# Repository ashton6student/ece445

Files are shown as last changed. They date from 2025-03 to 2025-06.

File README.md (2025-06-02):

# VR Gloves Project

Note: each subfolder has its own `README.md` file that forms the ECE 445 notebook, in addition to this top-level file.

## Overview

The VR Gloves project aims to create a pair of wearable hand-tracking gloves for VR applications, compatible with popular VR systems like Meta Quest 2. The gloves utilize perpendicular Hall effect sensors and magnets for finger flex tracking, a servo-based haptic feedback system, and BLE communication to interact with Unity applications.

## Inspirations

This project is inspired by LucidGloves, an open-source VR glove. This project specifically attempts to take the good things from V3 and the good things from V5 to make our own unique solution. Specifically, it uses the badge reel idea from V3 and the hall-effect magnet solution from the V5 and combines them together.

## Problem Statement

Modern VR devices often rely on handheld controllers that do not fully immerse the user in the virtual environment. While some high-end solutions like the Valve Index offer partial finger tracking, most affordable options still use conventional button-based input. The goal of this project is to develop a more immersive and affordable solution using DIY components.

## Key Features

- **Wireless Communication:** Uses BLE to transmit hand data to Unity applications.
- **Finger Tracking:** Perpendicular Hall effect sensors measure finger curl using magnetic field angle changes.
- **Haptic Feedback:** Servo motors lock the badge reels, restricting finger movement to provide haptic feedback.
- **Integrated VR Interaction:** Uses Unity's XR Interaction Toolkit to allow for these gloves to be developed in a VR scene and can be deployed to a VR headset.

## System Design

The VR gloves consist of five main subsystems:

### 1. Power Subsystem

- Uses a 7.4V Li-ion battery stepped down to 5V and 3.3V using LDO regulators.
- Provides stable power for ESP32-S3, hall effect sensors, and servo motors.

### 2. Sensor Subsystem

- Perpendicular Hall effect sensors paired with magnets on each finger track the degree of bend.
- Quest Controller used for hand positioning.
- Haptic feedback provided by servos locking badge reels.

### 3. MCU Subsystem

- Uses ESP32-S3 for data acquisition, BLE communication, and haptic control.
- Converts raw sensor data into a usable format in Unity.
- Transmits data via BLE to Unity with low latency (<20ms).

### 4. Controller Subsystem

- Features a thumb joystick and push buttons mounted on the index finger.
- Allows for conventional VR controller actions.
- Data is transmitted to Unity using the BLE protocol.

### 5. Software Subsystem

- Integrates with Unity using the XR Interaction Toolkit for virtual scene deployment.
- Virtual scene containing objects with colliders to test interaction.
- BLE data mapped to virtual hand movements and actions.
- Collision detection triggers haptic feedback via BLE.

## Code Structure

```
project_root/
├── Unity Files/       # Unity project and scenes
├── PCB Files/         # PCB schematics and board files
├── Arduino Files/     # Arduino sketches for glove firmware
├── 3D Files/          # 3D models and assets for Unity
├── Bluetooth Files/   # BLE communication scripts and libraries
├── myenv/             # Virtual environment for Python utilities
└── README.md          # Project documentation
```

### Arduino Files and Bluetooth Files

- Contains Arduino sketches for ESP32 to handle BLE communication and haptic control.
- Implements data acquisition from Hall effects and joystick inputs.
- Supports BLE wireless communication for real-time data transfer.

### Unity Files

- Unity scripts for receiving BLE data and controlling virtual hands.
- Includes a test scene for verifying glove performance.

### 3D Files

- 3D files for the glove parts.

### PCB Files

- KiCAD files for the PCBs in our project.

## Installation

1. Flash the ESP32 with the provided firmware in the `firmware/glove_controller/` directory.
2. Run the BLE Python bridge script located in `Bluetooth Files/`. You may need com2com software to simulate serial ports. Be sure to activate the Python virtual environment in `myenv/` and install required packages.
3. Open the Unity project from the `Unity Files/` folder.
4. Run the scene to test the glove inputs.

## Usage

- Wear the gloves and ensure they are powered on.
- Start the Unity scene and observe hand movement tracking.
- Test grabbing and manipulating virtual objects to validate haptic feedback.

## Future Improvements

- Enhanced haptic feedback.
- Integration with more VR platforms like SteamVR.
- Improved latency optimization in BLE communication.

## Authors

- Ashton Billings
- Hamza Lutfi
- Aditya Nebhrajani

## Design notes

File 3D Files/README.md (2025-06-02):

# 3D Files

## Project Overview

This folder contains a collection of 3D model files for various components for the VR glove project. The files are organized into subfolders based on their functionality or component type. Take the most recent version as the current working version.

## Directory Structure

```
3D Files/
├── ReelCoin/
├── FingerTip/
├── HapticsSystem/
├── BreadboardMount/
├── ReelGuide/
├── GloveMount/
└── Z.Misc/
```

### Subfolder Descriptions

- **ReelCoin/**: Contains STL files for different versions of a circular reel coin component.
- **FingerTip/**: Various iterations of the fingertip component.
- **HapticsSystem/**: 3D models for the haptic feedback system, containing several versioned files.
- **BreadboardMount/**: Models for mounting the PCB, battery, and related electronics.
- **ReelGuide/**: STL files for guiding or housing reels, with multiple versions available.
- **GloveMount/**: Mounting components for a glove-based setup, with multiple iterations.
- **Z.Misc/**: Miscellaneous components, including custom reels, gear models, and a pot holder.

## Usage

1. Inspect the STL files using 3D modeling software (e.g., Blender, Fusion 360) to verify dimensions.
2. Print using a 3D printer with compatible filament (e.g., PLA, ABS).
3. Adjust the model scale and orientation as needed before slicing.

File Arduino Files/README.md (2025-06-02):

# Arduino Project README

## Project Overview

This folder contains various Arduino-based test sketches used throughout the development of the VR glove system. Each subfolder represents a different development or testing checkpoint. While several sketches were created for experimenting with sensor inputs, BLE, and motor control, the current active version is located in the `ece445Arduino5` folder.

### Components:

- ESP32 microcontroller
- Joystick module
- Push buttons
- Servo motor
- Potentiometer

### Development History

```
Arduino Files/
├── ece445PlatformIO/                # PlatformIO testing checkpoint for ESP32
│   ├── src/                         # Source files
│   │   └── main.cpp                 # Main application code
│   └── platformio.ini               # PlatformIO configuration file
├── ArduinoInoFiles/                 # Traditional Arduino sketches
│   ├── ece445Arduino/               # Initial sketch
│   │   └── ece445Arduino.ino        # Primary Arduino sketch
│   ├── ece445Arduino2/              # Development checkpoints
│   ├── ece445Arduino3/              # Development checkpoints
│   ├── ece445Arduino4/              # Development checkpoints
│   ├── ece445Arduino5/              # Current BLE version
│   └── ece445Arduino6/              # Current serial version
```

## Installation

1. Clone or download the repository.
2. Open the desired `.ino` file in the Arduino IDE:
   - Use `ece445Arduino5` for BLE communication.
   - Use `ece445Arduino6` for serial communication.
3. Connect your ESP32 board to your computer via USB.
4. In the Arduino IDE, select the correct board type and COM port.
5. Click the Upload button to flash the code to your ESP32.

## Usage

The firmware sketches support both BLE (Bluetooth Low Energy) and wired serial communication, enabling wireless data transmission and control.

1. Upon startup, the ESP32 initializes the sensors and sets up the joystick and servo control.
2. Joystick data and button states are transmitted over serial at 115200 baud.
3. Use the joystick to control the servo and monitor sensor readings in the serial monitor.
4. BLE support can be integrated from `../Bluetooth Files`.

## Dependencies

- Arduino framework for ESP32
- ESP32Servo library

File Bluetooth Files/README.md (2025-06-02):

# Bluetooth Serial Bridge and ESP32 BLE API

## Overview

This folder consists of a Bluetooth serial bridge for communication between an ESP32 device and a host machine, along with an ESP32 Bluetooth API for setting up BLE communication. The folder is divided into two main components:

1. **Bluetooth Serial Bridge (Python)** - Establishes a Bluetooth connection between the ESP32 and a host PC.
2. **ESP32 Bluetooth API (Arduino)** - Sets up a BLE server on the ESP32 to facilitate communication with the host PC.

## Folder Structure

```
Bluetooth Files/
├── bluetooth_serial_bridge/
│   ├── bluetooth_serial_bridge.py        # Python script for Bluetooth serial bridge
│   └── test_bridge_legacy_app.py         # Placeholder for future integration with Unity's legacy COM code
└── esp32_bluetooth_api/
    └── bluetooth_api/
        └── bluetooth_api.ino             # Arduino sketch for BLE communication on ESP32
```

## Features

- Bidirectional Bluetooth communication using BLE.
- Virtual serial port support for both Windows and macOS.
- Real-time data transmission between the host and ESP32.

## Setup Instructions

### Prerequisites

- Python 3.8+
- `bleak` library for Bluetooth communication
- `pyserial` library for serial communication
- Arduino IDE for programming the ESP32

### Installing Dependencies

```bash
pip install bleak pyserial
```

### Running the Bridge

1. Upload the `bluetooth_api.ino` to your ESP32 using the Arduino IDE.
2. Run the Python bridge script:

```bash
python bluetooth_serial_bridge.py
```

3. Use the test script to send messages:

```bash
python test_bridge_legacy_app.py
```

## Usage

- The bridge script will automatically detect the OS and set up a virtual serial port.
- The test script sends user-inputted strings and displays responses from the ESP32.

## Troubleshooting

- Ensure that the COM port is correctly configured in the script for Windows.
- Check the BLE device name and UUIDs if connection fails.

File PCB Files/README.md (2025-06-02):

# PCB Project Overview

This repository contains the design files for two PCBs: **ESP32** and **Hall-Effect Sensor**. Both projects were designed using KiCad and include schematic files, PCB layouts, backups, and Gerber files for manufacturing.

## Project Structure

The repository is structured as follows:

```
PCB Files/
├── ESP32/
│   ├── ESP32.kicad_pcb           # PCB layout file
│   ├── ESP32.kicad_sch           # Schematic file
│   ├── ESP32.kicad_pro           # KiCad project file
│   ├── gerbers/                  # Gerber files for PCB manufacturing
│   └── backups/                  # Backup versions of the project
├── hall-effect/
│   ├── hall-effect.kicad_pcb     # PCB layout file
│   ├── hall-effect.kicad_sch     # Schematic file
│   ├── hall-effect.kicad_pro     # KiCad project file
│   ├── gerbers/                  # Gerber files for PCB manufacturing
│   └── backups/                  # Backup versions of the project
└── __MACOSX/                     # System-generated files (can be ignored)
```

## ESP32 Project

The ESP32 PCB project is designed around the ESP32 microcontroller, featuring:

- BLE and Wi-Fi connectivity
- GPIO headers for peripherals
- Power management circuits

### Gerber Files

The Gerber files located in `ESP32/gerbers/` include:

- Copper layers (F_Cu, B_Cu)
- Silkscreen layers (F_Silkscreen, B_Silkscreen)
- Solder mask layers (F_Mask, B_Mask)
- Paste layers (F_Paste, B_Paste)
- Edge cuts for board outline
- Drill files (PTH, NPTH)

## Hall-Effect Project

This project is based on a Hall-effect sensor module, designed for magnetic field detection.

- Uses a Hall-effect sensor IC
- Signal conditioning circuitry
- Gerber Files

Similar structure to the ESP32 project with copper, silkscreen, mask, paste, edge cuts, and drill files.

## Backups

The `backups/` directories in each project folder contain automated KiCad backups, timestamped for version tracking.

## Usage

Open the project files using KiCad (version 6.x or later). To fabricate the PCBs, use the Gerber files located in the respective `gerbers/` folder.

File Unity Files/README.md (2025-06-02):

# Unity VR Project

## Overview

This Unity VR project is built using the XR Interaction Toolkit (version 3.0.7) and showcases a hand interaction demo. It serves as a foundational project for VR environments with hand tracking, hand-based interaction, and gesture control.

## Features

- **XR Interaction Toolkit (3.0.7)**: Utilizes Unity's toolkit for VR interaction.
- **Hands Interaction Demo**: Demonstrates the use of hand tracking, poke gestures, and interaction affordances.
- **VR Hand Rig**: Configured hand tracking for left and right hands with visual affordances.
- **Prefab Assets**: Includes various prefabs for hand interaction visualization and UI elements.
- **Custom Scripts**:
  - TransformSync.cs: Synchronizes object transformations.
  - ToggleGameObject.cs: Manages visibility toggling of objects.
  - PokeBlendShapeAnimator.cs: Animates hand poke gestures.
  - CollisionLogger.cs: Logs collisions detected by objects.
  - SerialFloatReader.cs: Reads floating-point data from a serial device.

## Installation

1. Clone the project to your Unity projects directory.
2. Open the project in Unity (version 2021.3 or higher recommended).
3. Import the XR Interaction Toolkit package via Unity Package Manager.

## Usage

- Load the `HandsDemoScene` from the `Assets/Samples/XR Interaction Toolkit/3.0.7/Hands Interaction Demo` folder.
- Press Play to explore the VR environment and interact with objects using hand gestures.
- Connect the VR headset and controllers to enable hand tracking.

## Scripts

- **HandsOneEuroFilterPostProcessor.cs**: Implements a post-processing filter for hand data.
- **PokeGestureDetector.cs**: Detects poke gestures and triggers associated actions.
- **PinchPointFollow.cs**: Updates the position of objects based on pinch gestures.
- **ObjectResetPlane.cs**: Resets objects to their initial positions when dropped.

## Troubleshooting

- Ensure the correct version of the XR Interaction Toolkit is installed.
- Verify that the VR headset is properly connected and configured.

## License

This project follows the standard Unity Asset Store license for included assets.

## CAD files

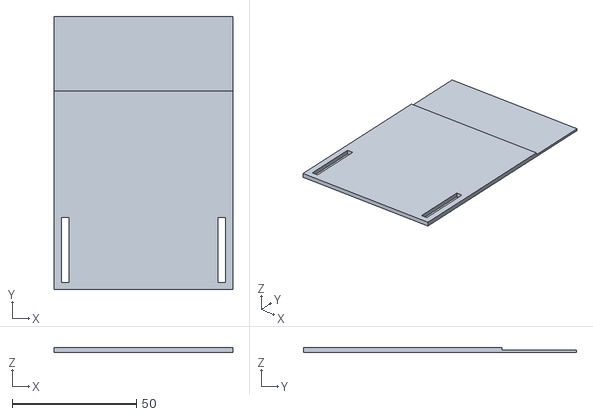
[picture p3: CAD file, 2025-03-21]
3D Files/BreadboardMount/BreadboardPlateV2.stl
72.0 x 110.0 x 2.00

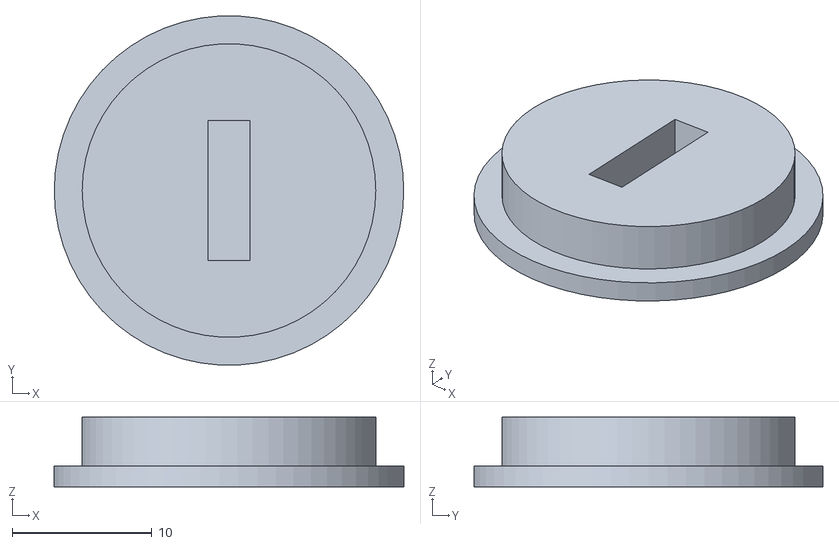
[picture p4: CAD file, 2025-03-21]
3D Files/ReelCoin/ReelCoinHallV1.stl
25.0 x 25.0 x 5.00

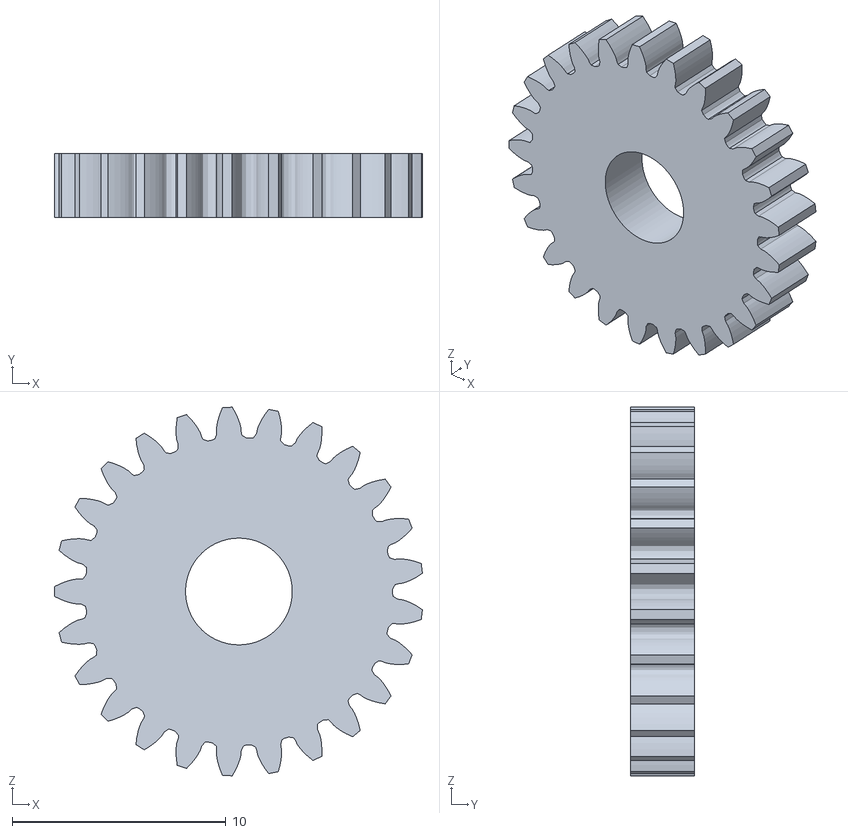
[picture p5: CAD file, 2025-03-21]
3D Files/Z.Misc/GearV1.stl
17.2 x 3.00 x 17.3

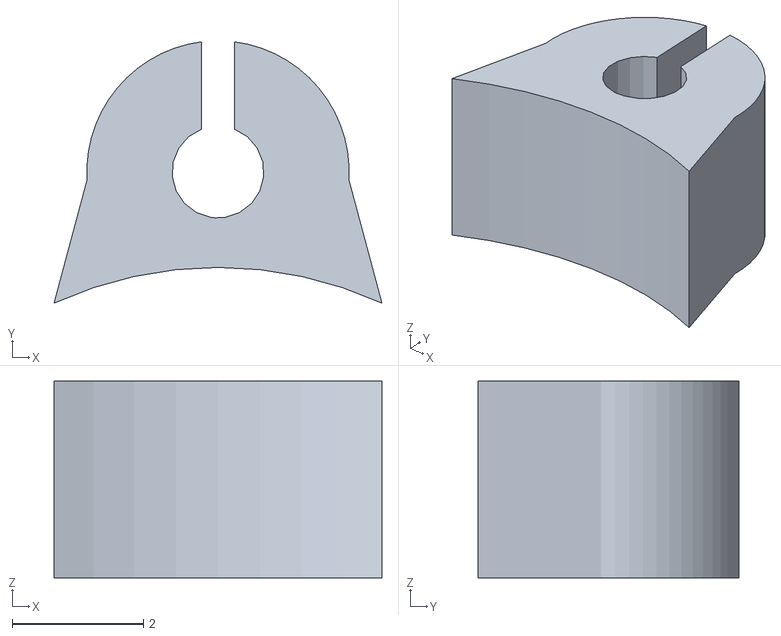
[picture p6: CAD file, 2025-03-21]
3D Files/Z.Misc/testreel.stl
5.00 x 3.98 x 3.00

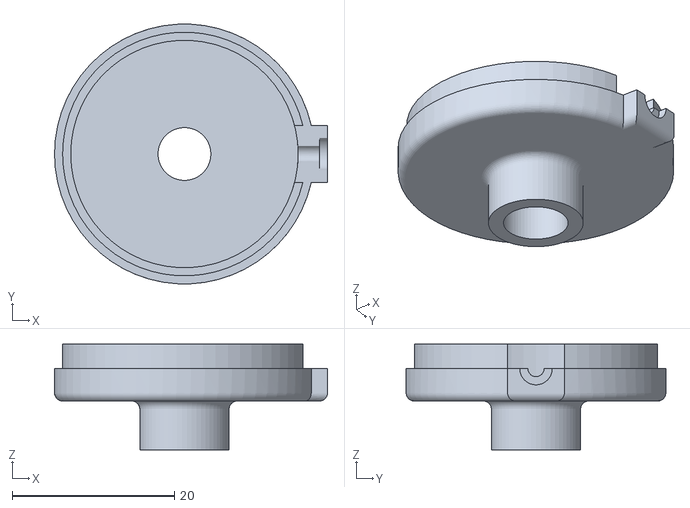
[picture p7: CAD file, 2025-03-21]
3D Files/Z.Misc/PotHolderV1.stl
33.6 x 32.0 x 13.0

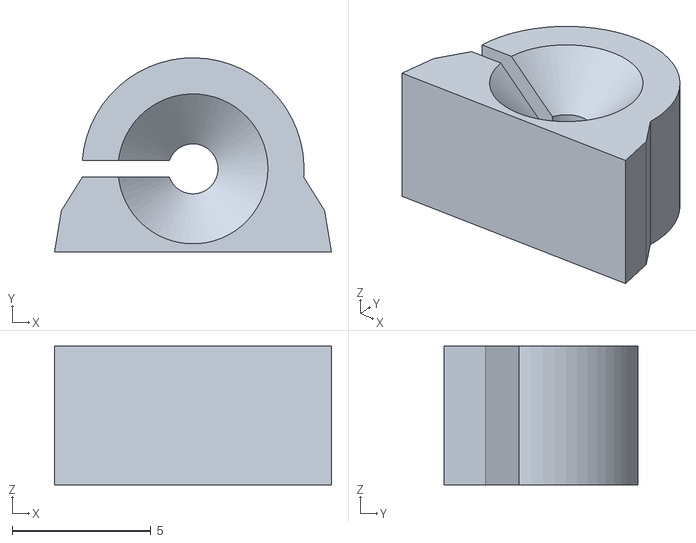
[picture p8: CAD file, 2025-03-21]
3D Files/ReelGuide/ReelV5.stl
9.98 x 7.00 x 5.00

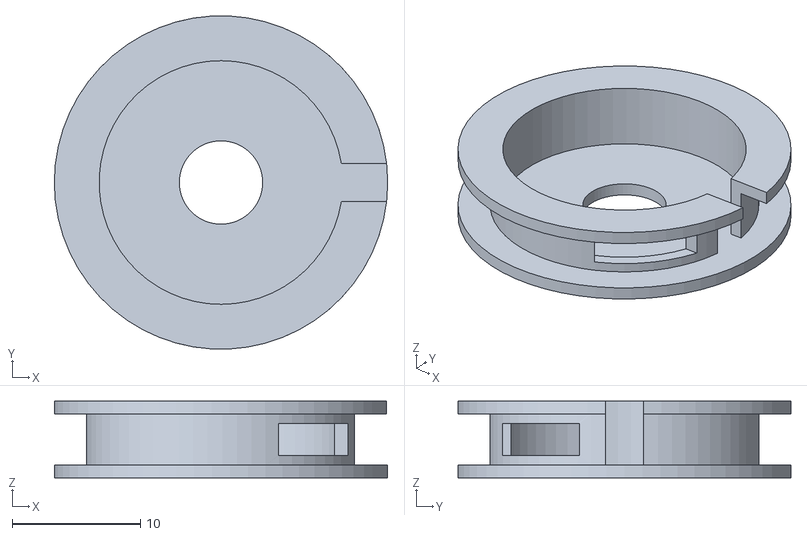
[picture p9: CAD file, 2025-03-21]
3D Files/Z.Misc/CustomReelV2.stl
26.0 x 26.0 x 6.00

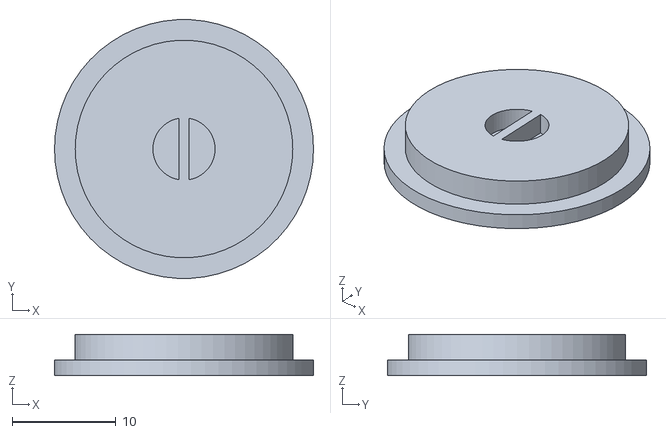
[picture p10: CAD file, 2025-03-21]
3D Files/ReelCoin/ReelCoinV9.stl
25.0 x 25.0 x 4.00

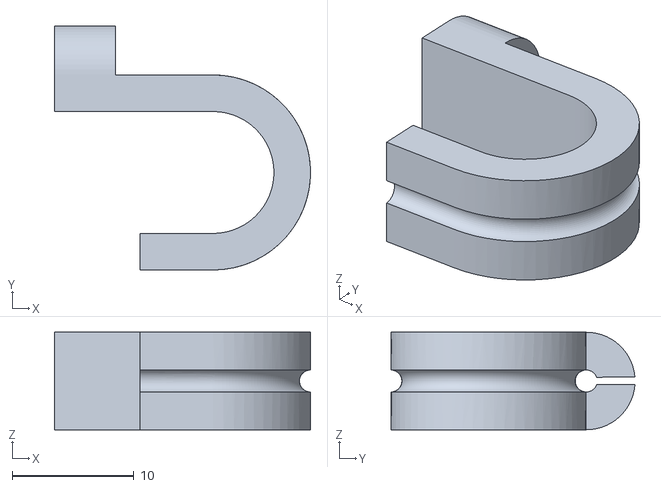
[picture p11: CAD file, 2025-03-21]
3D Files/FingerTip/FingerTipV10.stl
21.0 x 20.0 x 8.00

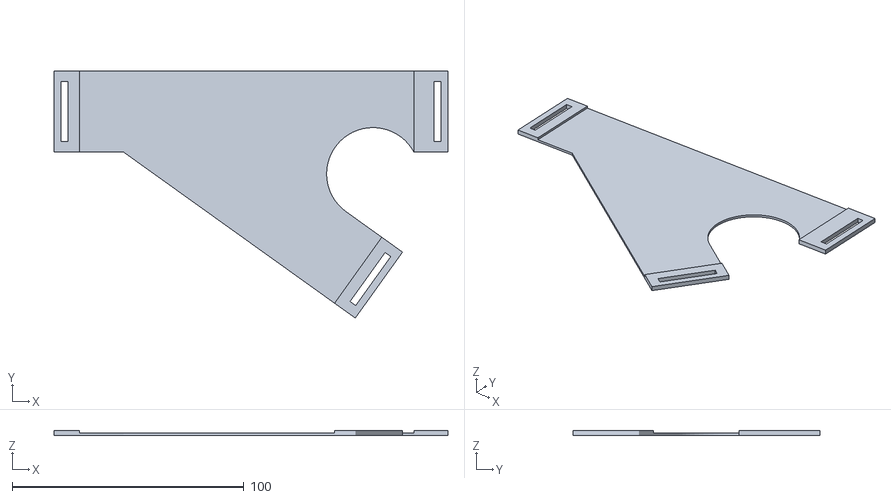
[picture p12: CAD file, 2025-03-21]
3D Files/GloveMount/PlateV9.stl
170.0 x 106.6 x 2.00

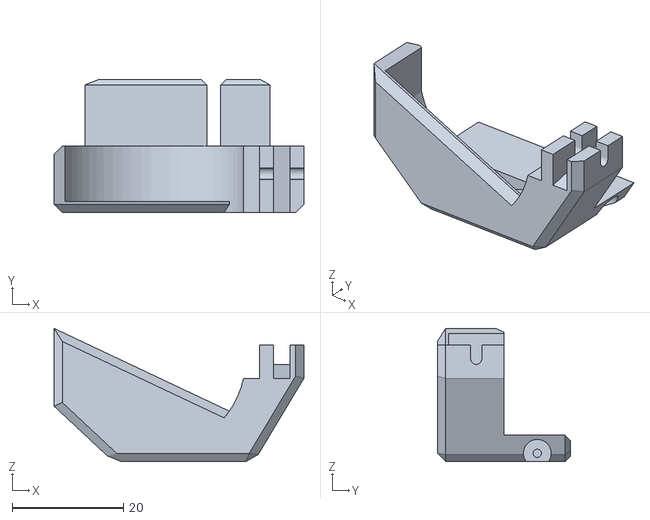
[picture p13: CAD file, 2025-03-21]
3D Files/HapticsSystem/HapticsSystemV9.stl
45.0 x 24.0 x 24.0

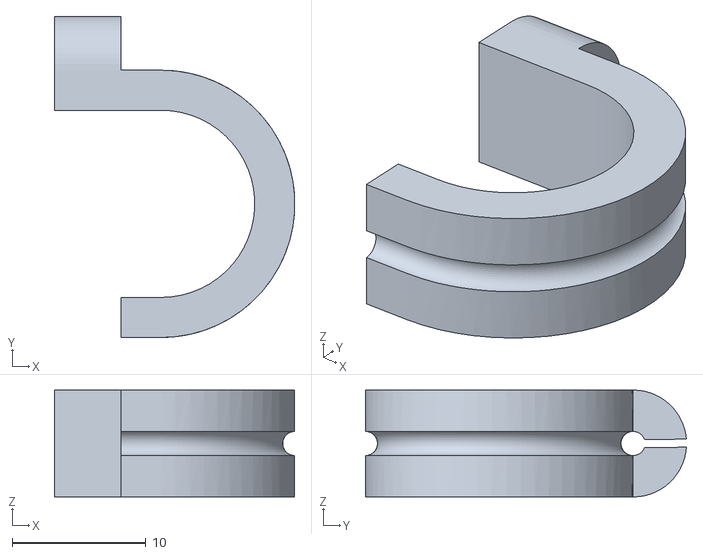
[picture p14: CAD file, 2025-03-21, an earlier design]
3D Files/FingerTip/FingerTipV8.stl
18.0 x 24.0 x 8.00

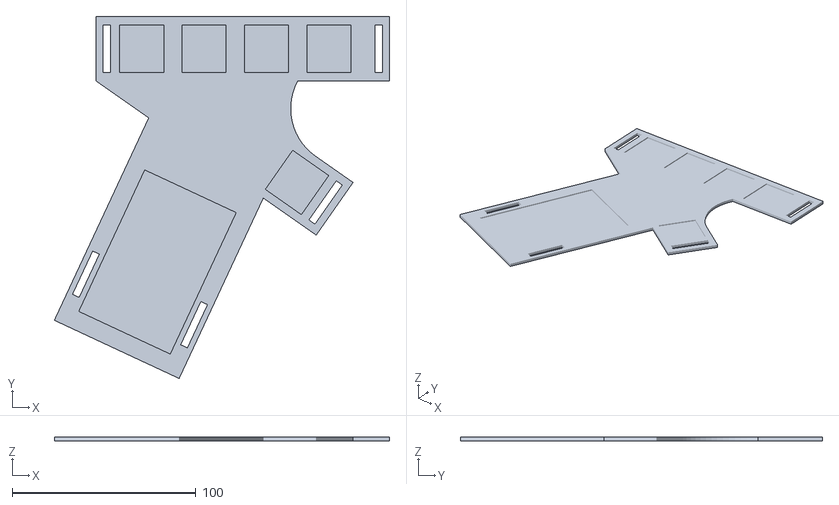
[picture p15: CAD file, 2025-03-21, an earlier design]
3D Files/GloveMount/PlateV8.stl
182.6 x 197.1 x 2.00

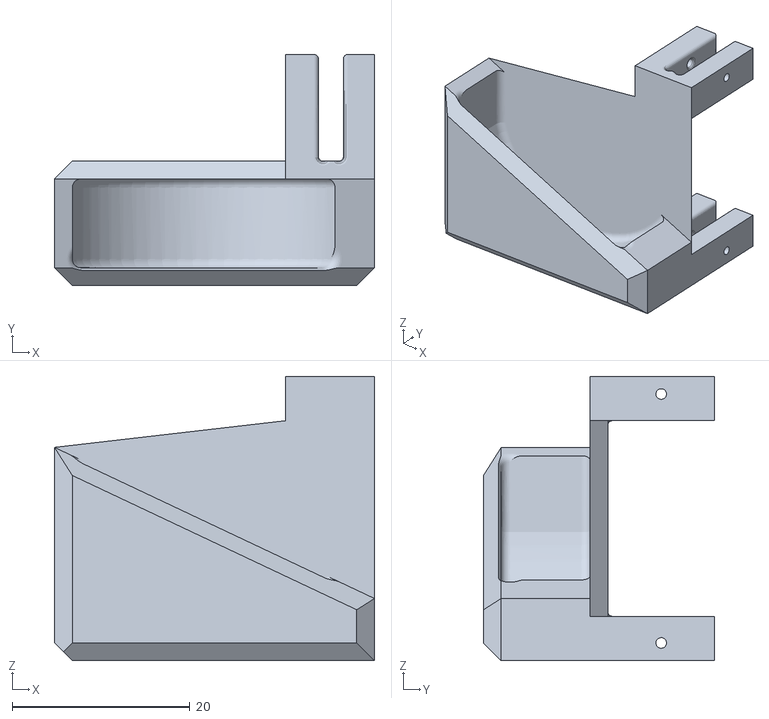
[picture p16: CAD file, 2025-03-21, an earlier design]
3D Files/HapticsSystem/HapticsSystemV1.stl
36.0 x 26.0 x 32.0

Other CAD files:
3D Files/ReelGuide/ReelV2.stl
3D Files/Z.Misc/CustomReelV1.stl
3D Files/BreadboardMount/BreadboardPlateV1.stl
3D Files/FingerTip/FingerTipV4.stl
3D Files/FingerTip/FingerTipV1.stl
3D Files/FingerTip/FingerTipV2.stl
3D Files/FingerTip/FingerTipV3.stl
3D Files/FingerTip/FingerTipV5.stl
3D Files/FingerTip/FingerTipV6.stl
3D Files/FingerTip/FingerTipV7.stl
3D Files/FingerTip/FingerTipV9.stl
3D Files/GloveMount/PlateV1.stl
3D Files/GloveMount/PlateV2.stl
3D Files/GloveMount/PlateV3.stl
3D Files/GloveMount/PlateV4.stl
3D Files/GloveMount/PlateV5.stl
3D Files/GloveMount/PlateV6.stl
3D Files/GloveMount/PlateV7.stl
3D Files/HapticsSystem/HapticsSystemV2.stl
3D Files/HapticsSystem/HapticsSystemV3.stl
3D Files/HapticsSystem/HapticsSystemV4.stl
3D Files/HapticsSystem/HapticsSystemV5.stl
3D Files/HapticsSystem/HapticsSystemV6.stl
3D Files/HapticsSystem/HapticsSystemV7.stl
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

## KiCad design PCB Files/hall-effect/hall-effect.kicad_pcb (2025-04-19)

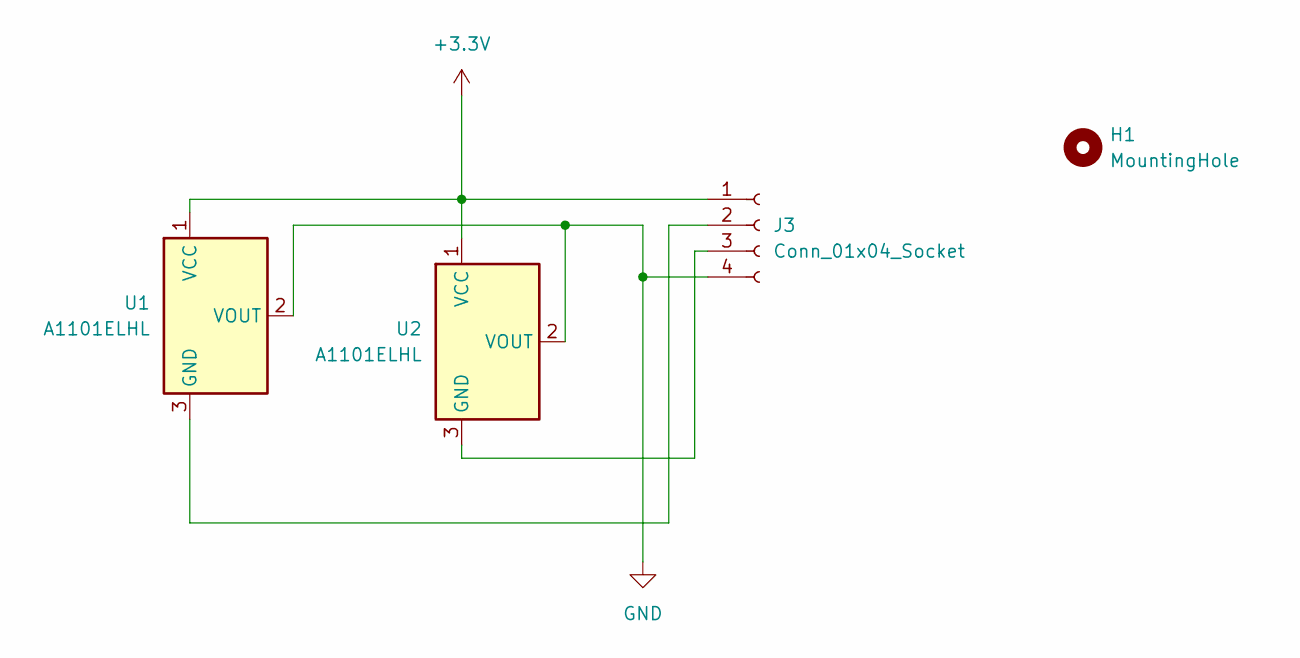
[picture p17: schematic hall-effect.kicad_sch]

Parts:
H1: MountingHole; MountingHole_2.2mm_M2
J3: Conn_01x04_Socket; JST_PH_S4B-PH-K_1x04_P2.00mm_Horizontal
U1, U2: A1101ELHL; TO-92Flat

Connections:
+3.3V: J3.1, U1.1 (VCC), U2.1 (VCC)
GND: J3.4, U1.2 (VOUT), U2.2 (VOUT)
unnamed: J3.2, U1.3 (GND)
unnamed: J3.3, U2.3 (GND)

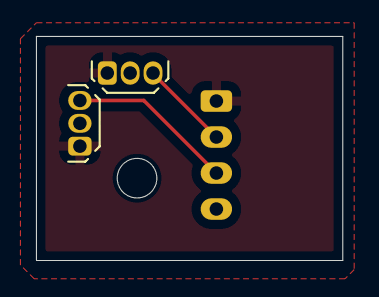
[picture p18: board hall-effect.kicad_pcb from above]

Board: 2 copper layers, 17.0 x 12.4 mm, 4 parts (1 on the bottom side), 4 nets.

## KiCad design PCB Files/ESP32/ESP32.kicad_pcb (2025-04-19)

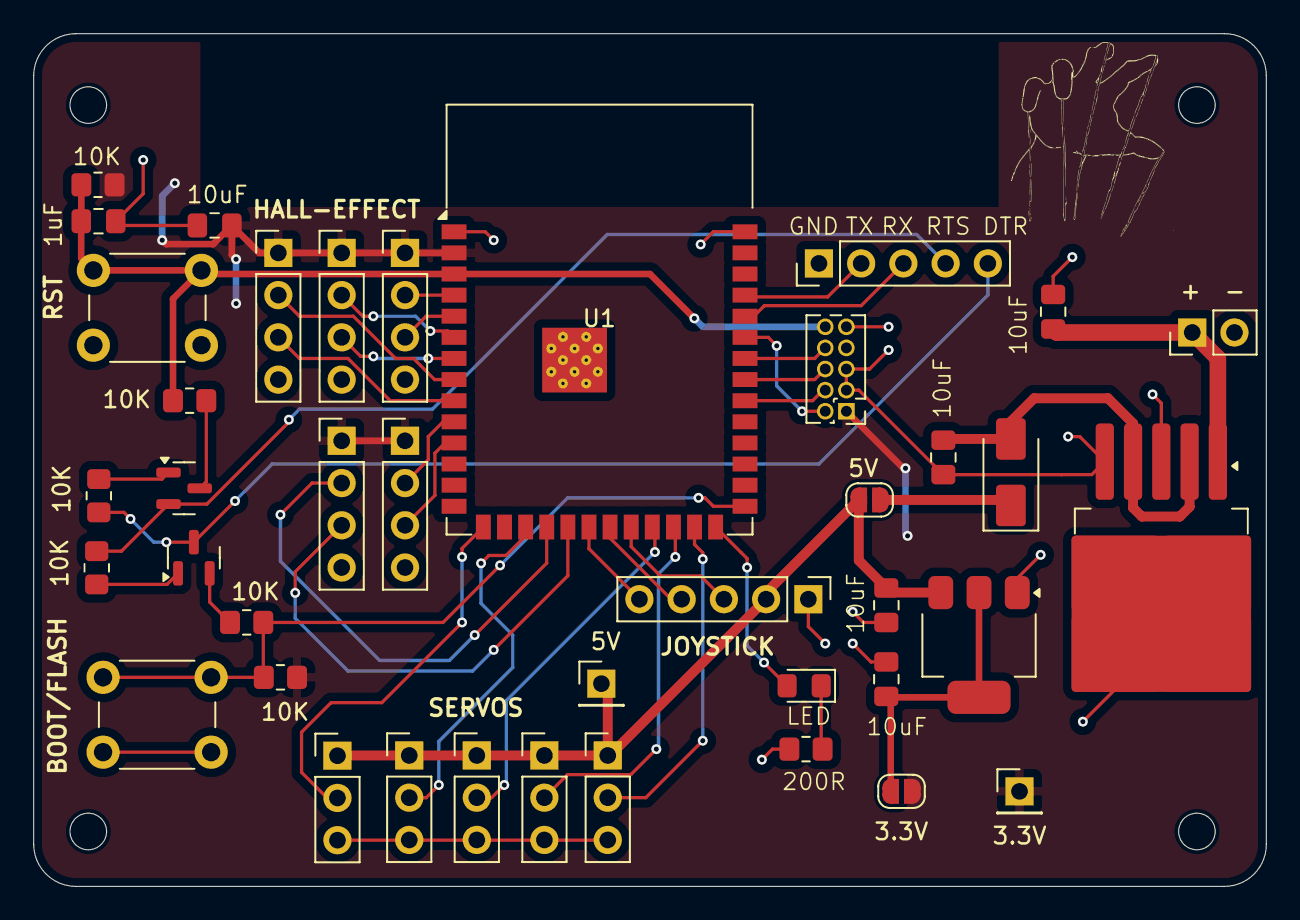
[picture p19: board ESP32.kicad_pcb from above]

Board: 2 copper layers, 74.1 x 51.3 mm, 44 parts (0 on the bottom side), 41 nets.

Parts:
+: 2S LiPo 7.4V 2000mAh; PinHeader_1x02_P2.54mm_Vertical
C1: 1uF; C_0805_2012Metric_Pad1.18x1.45mm_HandSolder
C2, C3, C5, C6, C7: 10uF; C_0805_2012Metric_Pad1.18x1.45mm_HandSolder
D1: LED; LED_0805_2012Metric_Pad1.15x1.40mm_HandSolder
D2: D_Schottky; D_SMA
H1, H2, H3, H4: MountingHole; MountingHole_2.2mm_M2
J1, J2, J3, J4, J5: Conn_01x03_Pin; PinHeader_1x03_P2.54mm_Vertical
J6, J11: Conn_01x05_Pin; PinHeader_1x05_P2.54mm_Vertical
J7: Conn_ARM_JTAG_SWD_10; PinHeader_2x05_P1.27mm_Vertical
J12, J13, J14, J15, J16: Conn_01x04_Pin; PinHeader_1x04_P2.54mm_Vertical
JP1, JP2: SolderJumper_2_Open; SolderJumper-2_P1.3mm_Open_RoundedPad1.0x1.5mm
Q1, Q2: SS8050; SOT-23
R1, R2, R3, R4, R8, R9: 10k; R_0805_2012Metric_Pad1.20x1.40mm_HandSolder
R5: 200; R_0805_2012Metric_Pad1.20x1.40mm_HandSolder
SW1, SW2: SW_Push; SW_PUSH_6mm
TP1, TP2: TestPoint; PinHeader_1x01_P2.54mm_Vertical
U1: ESP32-S3-WROOM-1
U2: AMS1117-3.3; SOT-223-3_TabPin2
U3: LM2596S-5; TO-263-5_TabPin3

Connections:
+3.3V: C7.2, J7.1 (VTref), J12.1, J13.1, J14.1, J15.1, J16.1, JP2.2 (B), R1.1, R4.2, TP2.1, U1.2 (3V3)
+5V: C3.1, J1.1, J2.1, J3.1, J4.1, J5.1, J11.2, JP1.2 (B), TP1.1, U2.3 (VI)
/0ADC: J13.3, U1.19 (IO11)
/1ADC: J11.5, U1.20 (IO12)
/2ADC: J11.4, U1.21 (IO13)
/3ADC: J11.3, U1.22 (IO14)
/4ADC: J15.2, U1.8 (IO15)
/5ADC: J15.3, U1.9 (IO16)
/6ADC: J16.2, U1.10 (IO17)
/7ADC: J16.3, U1.11 (IO18)
/21: J3.2, U1.23 (IO21)
/45: D1.2 (A), U1.26 (IO45)
/47: J4.2, U1.24 (IO47)
/48: J5.2, U1.25 (IO48)
/ADC2: J1.2, U1.15 (IO3)
/ADC3: J12.2, U1.4 (IO4)
/ADC4: J12.3, U1.5 (IO5)
/ADC5: J14.2, U1.6 (IO6)
/ADC6: J14.3, U1.7 (IO7)
/ADC8: J2.2, U1.17 (IO9)
/ADC9: J13.2, U1.18 (IO10)
/DTR: J6.5, Q2.3 (C), R2.1
/EN: C1.2, J7.10 (~RESET), R1.2, R8.2, SW2.1, U1.3 (EN)
/IO0: R4.1, R9.2, SW1.1, U1.27 (IO0)
/IO39: J7.4 (SWCLK/TCK), U1.32 (IO39)
/IO40: J7.6 (SWO/TDO), U1.33 (IO40)
/IO41: J7.8 (NC/TDI), U1.34 (IO41)
/IO42: J7.2 (SWDIO/TMS), U1.35 (IO42)
/RTS: J6.4, Q1.2 (E), R3.1
/RX: J6.3, U1.36 (RXD0)
/TX: J6.2, U1.37 (TXD0)
GND: +.2 (-), C1.1, C2.2, C3.2, C5.2, C6.2, C7.1, J1.3, J2.3, J3.3, J4.3, J5.3, J6.1, J7.3 (GND), J7.5 (GND), J7.9 (GNDDetect), J11.1, J12.4, J13.4, J14.4, J15.4, J16.4, R5.2, SW1.2, SW2.2, U1.1 (GND), U1.40 (GND), U1.41 (GND), U2.1 (GND), U3.3 (GND), U3.5 (~ON/OFF)
unnamed: +.1 (+), C5.1, U3.1 (VIN)
unnamed: D1.1 (K), R5.1
unnamed: C6.1, D2.2 (A), U3.2 (OUT), U3.4 (FB)
unnamed: D2.1 (K), JP1.1 (A)
unnamed: C2.1, JP2.1 (A), U2.2 (VO)
unnamed: Q1.1 (B), R2.2
unnamed: Q1.3 (C), R8.1
unnamed: Q2.1 (B), R3.2
unnamed: Q2.2 (E), R9.1

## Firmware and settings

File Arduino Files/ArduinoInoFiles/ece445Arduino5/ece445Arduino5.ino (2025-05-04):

#include <Arduino.h>
#include <math.h>

#include <BLEDevice.h>
#include <BLEUtils.h>
#include <BLEServer.h>
#include <BLE2902.h>

#define SERVICE_UUID        "6E400001-B5A3-F393-E0A9-E50E24DCCA9E"
#define CHARACTERISTIC_TX   "6E400003-B5A3-F393-E0A9-E50E24DCCA9E"
#define CHARACTERISTIC_RX   "6E400002-B5A3-F393-E0A9-E50E24DCCA9E"

// BLE stuff
BLECharacteristic* pTxCharacteristic;
bool deviceConnected = false;

#define RX_BUFFER_SIZE 256
char rxBuffer[RX_BUFFER_SIZE];
volatile int rxIndex = 0;
volatile bool rxLineReady = false;

#define TX_BUFFER_SIZE 256
char txBuffer[TX_BUFFER_SIZE];
int txIndex = 0;

class MyServerCallbacks : public BLEServerCallbacks {
  void onConnect(BLEServer* pServer) { deviceConnected = true; }
  void onDisconnect(BLEServer* pServer) { deviceConnected = false; }
};

class MyCallbacks : public BLECharacteristicCallbacks {
  void onWrite(BLECharacteristic* pCharacteristic) {
    const uint8_t* data = pCharacteristic->getData();
    size_t len = pCharacteristic->getLength();
    for (size_t i = 0; i < len && rxIndex < RX_BUFFER_SIZE - 1; ++i) {
      char c = (char)data[i];
      if (c == '\n') {
        rxBuffer[rxIndex] = '\0';
        rxLineReady = true;
        rxIndex = 0;
        break;
      }
      rxBuffer[rxIndex++] = c;
    }
  }
};

void BLEUartBufferedSend(const char* msg) {
  if (!deviceConnected || !pTxCharacteristic) return;
  pTxCharacteristic->setValue((uint8_t*)msg, strlen(msg));
  pTxCharacteristic->notify();
}

int BLEUartReceive(char* buf, int maxLen) {
  if (rxLineReady) {
    rxLineReady = false;
    int len = strlcpy(buf, rxBuffer, maxLen);
    return len;
  }
  return 0;
}

// Hardware setup
const int NUM_SENSORS = 5;
const int xPins[NUM_SENSORS] = {15, 6, 4, 10, 17};
const int yPins[NUM_SENSORS] = {16, 7, 5, 11, 18};

const int ledPin = 45;
const int joyXPin = 14;
const int joyYPin = 13;
const int NUM_BUTTONS = 1;
const int buttonPins[NUM_BUTTONS] = {12};

float alpha = 0.3;
float threshold = 2.0;
float tolerance = 5.0;
const unsigned long debounceDelay = 50;

// Joystick smoothing
float joyXFiltered = 0;
float joyYFiltered = 0;
float joystickAlpha = 0.3;
float joystickThreshold = 5.0;

// Joystick calibration
float joyXCenter = 2048.0;
float joyYCenter = 2048.0;
float joyXRange = 2048.0;
float joyYRange = 2048.0;

// State
int pressCount = 0;
bool joystickFlag = false;
bool useOverride = false;

struct SensorPair {
  int xPin;
  int yPin;
  float xMin, xMax, yMin, yMax;
  float xFiltered, yFiltered;
  float lower, upper;
  float w;
  float mapped;
};

SensorPair sensors[NUM_SENSORS];

struct Button {
  bool currentState;
  bool lastState;
  bool debouncedState;
  unsigned long lastDebounceTime;
};

Button buttons[NUM_BUTTONS];

const float offsets[NUM_SENSORS] = {0.0, 0.2, 0.4, 0.6, 0.8};
float overrideValues[NUM_SENSORS];
const unsigned long cycleDuration = 1000;
unsigned long startTime;

void handleButtonPress(int buttonIndex) {
  if (buttonIndex == 0) {
    if (pressCount == 0) {
      pressCount = 1;
      for (int i = 0; i < NUM_SENSORS; i++) {
        sensors[i].lower = sensors[i].w;
      }
    } else if (pressCount == 1) {
      pressCount = 0;
      for (int i = 0; i < NUM_SENSORS; i++) {
        sensors[i].upper = sensors[i].w;
      }
    }
  }
}

void generateOverrideValues() {
  unsigned long elapsed = (millis() - startTime) % cycleDuration;
  float rampValue = (float)elapsed / cycleDuration;
  for (int i = 0; i < NUM_SENSORS; i++) {
    float offsetValue = rampValue + offsets[i];
    if (offsetValue > 1.0) offsetValue -= 1.0;
    overrideValues[i] = offsetValue;
  }
}

void setup() {
  Serial.begin(115200);

  BLEDevice::init("ESP32-Finger-Sensors");
  BLEServer* pServer = BLEDevice::createServer();
  pServer->setCallbacks(new MyServerCallbacks());

  BLEService* pService = pServer->createService(SERVICE_UUID);

  pTxCharacteristic = pService->createCharacteristic(
    CHARACTERISTIC_TX,
    BLECharacteristic::PROPERTY_NOTIFY
  );
  pTxCharacteristic->addDescriptor(new BLE2902());

  BLECharacteristic* pRxCharacteristic = pService->createCharacteristic(
    CHARACTERISTIC_RX,
    BLECharacteristic::PROPERTY_WRITE | BLECharacteristic::PROPERTY_WRITE_NR
  );
  pRxCharacteristic->setCallbacks(new MyCallbacks());

  pService->start();
  pServer->getAdvertising()->start();

  Serial.println("BLE UART Ready");

  pinMode(ledPin, OUTPUT);
  pinMode(joyXPin, INPUT);
  pinMode(joyYPin, INPUT);

  for (int i = 0; i < NUM_BUTTONS; i++) {
    pinMode(buttonPins[i], INPUT);
    buttons[i] = {LOW, LOW, LOW, 0};
  }

  for (int i = 0; i < NUM_SENSORS; i++) {
    sensors[i].xPin = xPins[i];
    sensors[i].yPin = yPins[i];
    int xInit = analogRead(sensors[i].xPin);
    int yInit = analogRead(sensors[i].yPin);
    sensors[i].xMin = sensors[i].xMax = xInit;
    sensors[i].yMin = sensors[i].yMax = yInit;
    sensors[i].xFiltered = xInit;
    sensors[i].yFiltered = yInit;
    sensors[i].lower = 0;
    sensors[i].upper = 0;
    sensors[i].w = 0;
    sensors[i].mapped = 0;
  }

  // --- Joystick center calibration ---
  joyXFiltered = analogRead(joyXPin);
  joyYFiltered = analogRead(joyYPin);
  joyXCenter = joyXFiltered;
  joyYCenter = joyYFiltered;

  joyXRange = min(joyXCenter, (float)(4095.0) - joyXCenter);
  joyYRange = min(joyYCenter, (float)(4095.0) - joyYCenter);


  if (joyXRange < 1.0) joyXRange = 2048.0;
  if (joyYRange < 1.0) joyYRange = 2048.0;

  startTime = millis();
}

void loop() {
  unsigned long currentTime = millis();

  // --- Button Debouncing ---
  for (int i = 0; i < NUM_BUTTONS; i++) {
    buttons[i].currentState = digitalRead(buttonPins[i]);
    if (buttons[i].currentState != buttons[i].lastState) {
      buttons[i].lastDebounceTime = currentTime;
    }
    if ((currentTime - buttons[i].lastDebounceTime) > debounceDelay) {
      if (buttons[i].currentState != buttons[i].debouncedState) {
        buttons[i].debouncedState = buttons[i].currentState;
        if (buttons[i].debouncedState == LOW) {
          handleButtonPress(i);
        }
      }
    }
    buttons[i].lastState = buttons[i].currentState;
  }

  // --- Sensor Processing ---
  for (int i = 0; i < NUM_SENSORS; i++) {
    SensorPair &s = sensors[i];
    float x = analogRead(s.xPin);
    float y = analogRead(s.yPin);
    float xNext = alpha * x + (1 - alpha) * s.xFiltered;
    float yNext = alpha * y + (1 - alpha) * s.yFiltered;

    if (abs(xNext - s.xFiltered) > threshold) s.xFiltered = xNext;
    if (abs(yNext - s.yFiltered) > threshold) s.yFiltered = yNext;

    if (s.xFiltered < s.xMin) s.xMin = s.xFiltered;
    if (s.xFiltered > s.xMax) s.xMax = s.xFiltered;
    if (s.yFiltered < s.yMin) s.yMin = s.yFiltered;
    if (s.yFiltered > s.yMax) s.yMax = s.yFiltered;

    float xMid = (s.xMax + s.xMin) / 2.0;
    float xHalf = (s.xMax - s.xMin) / 2.0;
    float xNorm = (s.xFiltered - xMid) / xHalf;
    float yMid = (s.yMax + s.yMin) / 2.0;
    float yHalf = (s.yMax - s.yMin) / 2.0;
    float yNorm = (s.yFiltered - yMid) / yHalf;

    s.w = atan2(yNorm, xNorm) * 180.0 / PI + 180.0;

    const float adjustedTolerance = 25;
    float safeLower = fmod(s.lower - adjustedTolerance + 360.0, 360.0);
    float safeRange = fmod(s.upper - safeLower + 360.0, 360.0);
    float safeDelta = fmod(s.w - safeLower + 360.0, 360.0);

    s.mapped = (safeDelta > safeRange) ? 1.0 : safeDelta / safeRange;
  }

  if (useOverride) generateOverrideValues();

  // --- Joystick smoothing ---
  int rawJoyX = analogRead(joyXPin);
  int rawJoyY = analogRead(joyYPin);

  float joyXNext = joystickAlpha * rawJoyX + (1.0 - joystickAlpha) * joyXFiltered;
  float joyYNext = joystickAlpha * rawJoyY + (1.0 - joystickAlpha) * joyYFiltered;

  if (abs(joyXNext - joyXFiltered) > joystickThreshold) joyXFiltered = joyXNext;
  if (abs(joyYNext - joyYFiltered) > joystickThreshold) joyYFiltered = joyYNext;

  // --- Normalize using calibrated center ---
  float joyXNormalized = (joyXFiltered - joyXCenter) / joyXRange;
  float joyYNormalized = (joyYFiltered - joyYCenter) / joyYRange;
  joyXNormalized = constrain(joyXNormalized, -1.0, 1.0);
  joyYNormalized = constrain(joyYNormalized, -1.0, 1.0);

  // --- Output ---
  char msg[128];
  int index = 0;
  for (int i = 0; i < NUM_SENSORS; i++) {
    float val = useOverride ? overrideValues[i] : sensors[i].mapped;
    if (isnan(val)) val = 0.0;
    index += snprintf(msg + index, sizeof(msg) - index, "%.3f,", val);
  }
  index += snprintf(msg + index, sizeof(msg) - index, "%.2f,%.2f,", joyXNormalized, joyYNormalized);
  index += snprintf(msg + index, sizeof(msg) - index, "%d\n", buttons[0].debouncedState ? 0 : 1);

  BLEUartBufferedSend(msg);
  Serial.print(msg);

  delay(20);
}

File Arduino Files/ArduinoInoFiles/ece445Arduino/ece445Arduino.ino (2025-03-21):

#include <ESP32Servo.h>  // Use the ESP32 Servo library

// Button Pins
const int inputPin1 = 25;  // GPIO26 (Top Button - 'W')
const int inputPin2 = 26;  // GPIO25 (Bottom Button - 'S')

// Servo Pin
const int servoPin = 27;   // GPIO27 (Servo Signal Pin)

// Joystick Pins
const int VRX_PIN = 34;  // X-axis analog input (ADC1)
const int VRY_PIN = 35;  // Y-axis analog input (ADC1)
const int SW_PIN = 13;   // Joystick button input (digital)

//Potentiometer Pin
const int Pot1 = 14;
// Servo Object
Servo myServo;

void setup() {
    Serial.begin(115200);         // Start serial communication
    pinMode(inputPin1, INPUT);    // Set GPIO26 as INPUT (Top Button)
    pinMode(inputPin2, INPUT);    // Set GPIO25 as INPUT (Bottom Button)
    pinMode(Pot1, INPUT);    // Set GPIO14 as INPUT (Bottom Button)
    pinMode(SW_PIN, INPUT_PULLUP); // Enable pull-up resistor for joystick button

    myServo.attach(servoPin, 500, 2500); // Attach servo with pulse width limits
    myServo.write(0);                   // Initialize servo to 0° (locked position)
}

void loop() {
    // Read button states
    int topButton = digitalRead(inputPin1);     // Read 'W' button
    int bottomButton = digitalRead(inputPin2);  // Read 'S' button

    // Read joystick values
    int xValue = analogRead(VRX_PIN); // Read X-axis
    int yValue = analogRead(VRY_PIN); // Read Y-axis
    int buttonState = digitalRead(SW_PIN); // Read joystick button state


    //Read Pot
    int pot1 = analogRead(Pot1);

    // Servo control using buttons
    if (topButton == HIGH && bottomButton == LOW) {
        myServo.write(0);  // Rotate servo to 180° (spin forward)
    } 
    else if (bottomButton == HIGH && topButton == LOW) {
        myServo.write(110);   // Move servo to 0° (lock/stop)
    }

    // Print values to Serial Monitor
    Serial.print("w: ");
    Serial.print(topButton);
    Serial.print(" | s: ");
    Serial.print(bottomButton);
    Serial.print(" | 1: ");
    Serial.print(pot1);
    Serial.print(" | X: ");
    Serial.print(xValue);
    Serial.print(" | Y: ");
    Serial.print(yValue);
    Serial.print(" | Joystick Button: ");
    Serial.println(buttonState == LOW ? "Pressed" : "Released");

    delay(100);  // Debounce delay
}

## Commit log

2025-03-21 added current work
    [BreadboardPlateV1.stl, BreadboardPlateV2.stl, CustomReelV1.stl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]
2025-03-21 fixed a name
    [BreadboardPlateV1.stl, BreadboardPlateV2.stl]
2025-03-27 added other arduino files
2025-03-27 fixed arduino file formatting issues for PlatformIO
    [ece445Arduino.ino, ece445Arduino2.ino, ece445Arduino3.ino]
2025-03-30 added multi buttons
2025-04-07 updated PCB
    [ESP32.kicad_sch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]
2025-04-07 New Hall effect module
    [hall-effect-B_Cu.gbr, hall-effect-B_Mask.gbr, hall-effect-B_Paste.gbr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]
2025-04-07 Trace thickness fixed on one of the servos
    [ESP32.kicad_pcb]
2025-04-07 Included Gerber files
    [ESP32-B_Cu.gbr, ESP32-B_Mask.gbr, ESP32-B_Paste.gbr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]
2025-04-19 Added print for debugging
2025-04-27 updated bridge code
    [pyvenv.cfg]
